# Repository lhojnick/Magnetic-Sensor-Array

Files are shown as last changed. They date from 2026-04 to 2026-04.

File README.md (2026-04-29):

# MAG PCB FINAL — Multi-Sensor Magnetometer Board

**Lab:** Coherent and Quantum Optics Lab, Purdue University  
**PI:** Dr. Elliott  
**Designer:** Luke Hojnicki  
**Primary User:** Chunya Wang  
**KiCad Version:** 10.0.1  
**Status:** Hardware validated, two-board system operational

---

## Overview

This repository contains everything needed to reproduce, operate, and extend the
multi-sensor magnetometer PCB developed for Dr. Elliott's quantum optics lab.

The system measures the 3-axis magnetic field vector (Bx, By, Bz) at **8 spatial
locations simultaneously** using two identical PCBs connected in series via FFC cable.
Each board carries four MMC5983MA AMR magnetometers arranged around a 30 mm radius
circular cutout, allowing the boards to be mounted concentrically around a cylindrical
experimental object (optical tube, glass cell, etc.).

```
Arduino Nano Every
       │
       ├── SDA / SCL / RST / 5V / 3.3V
       │
       ├── Board 0 ─ TCA9546A (0x70) ─┬── MMC5983MA #0  (channel 0)
       │              LM3940 LDO       ├── MMC5983MA #1  (channel 1)
       │                               ├── MMC5983MA #2  (channel 2)
       │                               └── MMC5983MA #3  (channel 3)
       │
       └── Board 1 ─ TCA9546A (0x71) ─┬── MMC5983MA #4  (channel 0)
                      LM3940 LDO       ├── MMC5983MA #5  (channel 1)
                                       ├── MMC5983MA #6  (channel 2)
                                       └── MMC5983MA #7  (channel 3)
```

---

## Repository Structure

```
MAG-PCB/
├── README.md                          ← this file
├── .gitignore
│
├── docs/
│   ├── magnetometer_report.tex        ← full lab report (LaTeX source)
│   ├── magnetometer_report.pdf        ← compiled report
│   └── design_notes.md               ← original circuit design document
│
├── firmware/
│   └── magnetometer/
│       ├── magnetometer.ino           ← main Arduino sketch
│       ├── mmc5983ma.h                ← MMC5983MA driver header
│       └── mmc5983ma.cpp              ← MMC5983MA driver implementation
│
├── python/
│   ├── logger.py                      ← USB-serial data logger (saves CSV)
│   └── requirements.txt
│
└── gerbers/
    ├── MAG PCB FINAL-F_Cu.gbr
    ├── MAG PCB FINAL-B_Cu.gbr
    ├── MAG PCB FINAL-F_Mask.gbr
    ├── MAG PCB FINAL-B_Mask.gbr
    ├── MAG PCB FINAL-F_Paste.gbr
    ├── MAG PCB FINAL-B_Paste.gbr
    ├── MAG PCB FINAL-F_Silkscreen.gbr
    ├── MAG PCB FINAL-B_Silkscreen.gbr
    ├── MAG PCB FINAL-Edge_Cuts.gbr
    └── MAG PCB FINAL-job.gbrjob       ← submit this to fab with all .gbr files
```

---

## Quick Start

### Hardware Setup

1. **Single board:** Connect the Arduino Nano Every to Board 0 via FFC cable.
   Confirm mux address `0x70` with the I2C scanner sketch.

2. **Two boards:** Connect Board 0 PIN_OUT → Board 1 PIN_IN with a
   **Type-B FFC cable** (Top-on-One-Side, Bottom-on-the-Other).
   Board 1 requires the A0 pin on its TCA9546A moved from GND → VCC
   to assign it address `0x71`. See the report (Section 6) for the
   rework procedure.

3. Power-on checklist:
   - Verify 3.3V at LDO output before connecting Arduino
   - Run I2C scanner — expect `0x70` (Board 0) and `0x71` (Board 1)
   - Scan each mux channel — expect `0x30` on all 8 channels

### Firmware

Open `firmware/magnetometer/magnetometer.ino` in Arduino IDE 2.x.

- Board: **Arduino Nano Every** (megaAVR Boards package)
- Registers Emulation: **None (ATMEGA4809)**
- Baud: **115200**

Upload and open Serial Monitor. You should see CSV output:
```
sensorID,Bx_G,By_G,Bz_G
0,0.2341,0.0123,-0.4412
...
7,0.2344,0.0125,-0.4415
```

### Data Logging (Python)

```bash
pip install -r python/requirements.txt
python python/logger.py --port COM3 --output data.csv
# Linux/Mac: --port /dev/ttyACM0
```

---

## Board Specifications

| Parameter | Value |
|---|---|
| Dimensions | 50 mm × 120 mm |
| Layer count | 2 (F_Cu / B_Cu) |
| Board thickness | 1.6 mm |
| Min trace width | 0.3 mm |
| Pad-to-pad clearance | 0.2 mm |
| KiCad version | 10.0.1 |

## I2C Address Map

| Device | Address | Notes |
|---|---|---|
| TCA9546A — Board 0 | `0x70` | A0 = GND (default) |
| TCA9546A — Board 1 | `0x71` | A0 = VCC (requires rework) |
| MMC5983MA (all) | `0x30` | Fixed; isolated per mux channel |

---

## Key Components

| Part | Function | Qty/board |
|---|---|---|
| MMC5983MA | 3-axis AMR magnetometer | 4 |
| TCA9546AD | 4-channel I2C mux | 1 |
| LM3940IMPX | 5V → 3.3V LDO | 1 |
| 2.7 kΩ resistors | I2C pull-ups | 11 |
| 1 µF ceramic caps | Sensor VDD bypass | 4 |
| 10 µF ceramic caps | Sensor CAP pin / mux VCC | 5 |
| 33 µF cap | LDO output | 1 |

---

## Known Issues / Future Work

- INT pin unused — firmware polls Meas_M_Done bit (adequate for ≤10 Hz)
- No on-chip temperature compensation — repeat SET/RESET for long runs
- FFC cable length sensitivity — reduce I2C to 100 kHz for cables > 30 cm
- Max 8 boards (32 sensors) before TCA9546A address space exhausted

---

## References

- MEMSIC MMC5983MA Datasheet, Rev. A
- Texas Instruments TCA9546A Datasheet, SCPS204
- Texas Instruments LM3940 Datasheet, SNOS386
- Arduino Nano Every: https://docs.arduino.cc/hardware/nano-every

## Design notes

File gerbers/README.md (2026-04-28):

# Gerbers

Generated from KiCad 10.0.1 on 2026-04-27.

## Files

| File | Layer | Function |
|---|---|---|
| `MAG PCB FINAL-F_Cu.gbr` | F_Cu (L1) | Top copper — all signal routing |
| `MAG PCB FINAL-B_Cu.gbr` | B_Cu (L2) | Bottom copper — ground/return paths |
| `MAG PCB FINAL-F_Paste.gbr` | F_Paste | Top solder paste (SMT stencil) |
| `MAG PCB FINAL-B_Paste.gbr` | B_Paste | Bottom solder paste |
| `MAG PCB FINAL-F_Silkscreen.gbr` | F_Silkscreen | Top component labels |
| `MAG PCB FINAL-B_Silkscreen.gbr` | B_Silkscreen | Bottom labels |
| `MAG PCB FINAL-F_Mask.gbr` | F_Mask | Top solder mask openings |
| `MAG PCB FINAL-B_Mask.gbr` | B_Mask | Bottom solder mask openings |
| `MAG PCB FINAL-Edge_Cuts.gbr` | Edge_Cuts | Board outline / routed profile |
| `MAG PCB FINAL-job.gbrjob` | — | Gerber job file (submit to fab) |

## Fab Specs (from job file)

- Board size: **50.05 mm × 120.05 mm**
- Layers: **2**
- Thickness: **1.6 mm**
- Min trace: **0.3 mm**
- Pad-to-pad: **0.2 mm**

## Ordering

Submit all `.gbr` files plus the `.gbrjob` to your PCB fabricator
(JLCPCB, PCBWay, OSH Park, etc.). The job file encodes all specifications
automatically.

For two-board assembly: order **2× quantity minimum**. Both boards use
identical Gerbers; the only hardware difference is the A0 address strap
on the TCA9546A (see `docs/magnetometer_report.pdf` Section 6).

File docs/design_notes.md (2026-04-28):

# Magnetometer Array PCB — Circuit Design Notes

**Project:** 4-Channel MMC5983MA Magnetometer Array with I²C Multiplexer  
**Controller:** Arduino Nano Every (ATmega4809)  
**CAD Tool:** KiCad  
**Date:** March 2026  

---

## 1. System Overview

This PCB measures the magnetic field surrounding a laser beam axis using
four MMC5983MA 3-axis magnetometers arranged symmetrically. The sensors are
positioned so that their individual magnetic field contributions cancel
spatially (gradiometric / differential arrangement). The system rapidly
cycles through each sensor using a TCA9546A I²C multiplexer, then computes
an aggregated magnetic field measurement.

---

## 2. Voltage Domain — Critical Design Constraint

**The MMC5983MA has an absolute maximum VDD of 3.6V.**

The Arduino Nano Every USB rail is 5V. The board therefore runs entirely on
the Arduino's 3.3V output pin. All pull-up resistors go to 3.3V, not 5V.

The TCA9546A I/O is 5.5V tolerant so the upstream side can safely interface
with the 5V Arduino, but the I²C pull-ups and all sensor power must be 3.3V.

The ATmega4809 VIH at 5V supply is nominally 3.5V — slightly above 3.3V.
In practice this works reliably due to Schmitt trigger hysteresis on the I²C
pins. If I²C failures occur, add a BSS138 N-channel FET level shifter pair.

**Never connect sensor VDD to the Arduino 5V pin.**

---

## 3. I²C Address Map

| Device | 7-bit Address | Bus Segment |
|---|---|---|
| TCA9546A (Board 0) | 0x70 | Upstream (Arduino bus) |
| TCA9546A (Board 1) | 0x71 | Upstream (Arduino bus) |
| MMC5983MA (all) | 0x30 (fixed) | Downstream, one channel at a time |

No address conflicts exist because each MMC5983MA is isolated on its own
downstream channel. The mux ensures only one sensor is on the upstream bus
at any time.

---

## 4. Pull-Up Resistor Strategy

**Value: 2.7 kΩ** (appropriate for bus lengths < 10 cm at 400 kHz)
**All pull-ups to 3.3V.**

| Bus Segment | SDA pull-up | SCL pull-up |
|---|---|---|
| Upstream (Arduino → mux) | R1 2.7kΩ | R2 2.7kΩ |
| Downstream Ch0 | R3 2.7kΩ | R4 2.7kΩ |
| Downstream Ch1 | R5 2.7kΩ | R6 2.7kΩ |
| Downstream Ch2 | R7 2.7kΩ | R8 2.7kΩ |
| Downstream Ch3 | R9 2.7kΩ | R10 2.7kΩ |

**Total: 10 pull-up resistors per board** (11 on the final design — R3 added
to the upstream SDA net as well).

Each downstream channel needs its own pull-ups because the TCA9546A is a
switch, not a buffer. When a channel is disconnected (switch open), that
downstream segment has no pull-ups unless they are present locally.

---

## 5. TCA9546A Channel Select Sequence

To read sensor N (0–3):

1. Write to TCA9546A (0x70): control byte = `(1 << N)` — enable channel N only
2. Communicate with MMC5983MA (0x30) — reaches only sensor N
3. Read measurement data
4. Write `0x00` to TCA9546A to deselect all channels
5. Repeat for next sensor

```
Write 0x70: 0x01  →  Read sensor 0 at 0x30
Write 0x70: 0x02  →  Read sensor 1 at 0x30
Write 0x70: 0x04  →  Read sensor 2 at 0x30
Write 0x70: 0x08  →  Read sensor 3 at 0x30
```

**Important:** A STOP condition must follow the control register write
before communicating with the downstream device (TCA9546A datasheet p14).

---

## 6. MMC5983MA Decoupling

Per datasheet application circuit:

| Pin | Cap | Value | Placement |
|-----|-----|---|---|
| VDD (pin 2) | Bypass | 1 µF | As close as possible to sensor |
| CAP (pin 10) | Required | 10 µF | Low-ESR ceramic; internal charge pump ref |

Do not omit the CAP pin capacitor — it is required for the internal charge
pump that drives the SET/RESET coil. The sensor will not function correctly
without it.

---

## 7. SET/RESET Coil Operation

The MMC5983MA contains an on-chip coil for re-magnetizing the Permalloy
sensing element. This is required to:

- Restore the sensor after exposure to strong external fields (SET)
- Enable offset cancellation via bridge output subtraction (SET + RESET)

**SET** (CONTROL0 bit 3 = 1):
- Magnetizes Permalloy in positive direction
- Issue at startup and periodically during long runs

**RESET** (CONTROL0 bit 4 = 1):
- Magnetizes Permalloy in negative direction
- Combined with SET measurement: B = (B_SET - B_RESET) / 2
- Cancels temperature-dependent bridge offset

Wait ≥ 1 µs after each pulse before triggering a measurement.

---

## 8. Fast I²C Polling Strategy

Target: ~1 kHz aggregate sample rate across all 4 sensors (250 Hz per sensor).

At 400 kHz I²C (Fast Mode):
- Channel select write: ~25 µs
- Measurement trigger + 2 ms conversion time (dominant)
- 7-byte burst read (18-bit output): ~20 µs
- Channel deselect: ~25 µs

Per-sensor total: ~2.1 ms → **~470 Hz per sensor / ~120 Hz aggregate**

To achieve higher rates: use CONTROL1 BW[1:0] = 0b11 (highest bandwidth,
lowest conversion time ~0.5 ms), or enable Continuous Measurement Mode
(CMM_EN) and poll status bit rather than triggering each time.

---

## 9. Layout Rules for Magnetic Quiet Zone

1. **No current loops near sensors.** All routing that carries meaningful
   current (power, USB, regulator) must be in the control section,
   physically separated from the sensor array.

2. **Tight bypass caps.** Place VDD and CAP bypass caps within 1 mm of
   sensor pads to minimize high-frequency current loop area.

3. **No ferromagnetic components** in the sensor section. Ceramic caps only.

4. **Bundle I²C channel traces** through any routing neck. Keep SDA/SCL
   pairs adjacent to minimize differential loop area.

5. **Mounting holes:** Use non-magnetic hardware (brass or nylon).
   Stainless steel screws near sensors will perturb readings.

---

## 10. Design Assumptions

- Arduino Nano Every operates at 5V USB; 3.3V rail supplies sensor circuit.
- Only one TCA9546A channel enabled at a time (no simultaneous operation).
- Laser environment does not produce fields exceeding ±8 G (sensor FSR).
- Room temperature operation (20–25°C); all parts rated to −40/+85°C.
- MMC5983MA SPI_SDO pin left floating in I²C mode (consistent with
  MEMSIC application circuit, p10–11 of datasheet).
- INT pins unused; firmware polls Meas_M_Done status bit.

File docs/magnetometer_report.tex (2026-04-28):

\documentclass[12pt]{article}

% ── Packages ──────────────────────────────────────────────────────────────────
\usepackage[margin=1in]{geometry}
\usepackage{graphicx}
\usepackage{float}
\usepackage{amsmath}
\usepackage{hyperref}
\usepackage{listings}
\usepackage{xcolor}
\usepackage{booktabs}
\usepackage{caption}
\usepackage{subcaption}
\usepackage{fancyhdr}
\usepackage{titlesec}
\usepackage{parskip}
\usepackage{enumitem}
\usepackage{siunitx}
\usepackage{array}
\usepackage{multirow}

% ── Code listing style ────────────────────────────────────────────────────────
\lstset{
  basicstyle=\ttfamily\small,
  keywordstyle=\color{blue!70!black},
  commentstyle=\color{gray},
  stringstyle=\color{red!70!black},
  numbers=left,
  numberstyle=\tiny\color{gray},
  frame=single,
  breaklines=true,
  captionpos=b,
  tabsize=2
}

% ── Header / Footer ───────────────────────────────────────────────────────────
\setlength{\headheight}{15pt}
\pagestyle{fancy}
\fancyhf{}
\rhead{Coherent \& Quantum Optics Lab --- Purdue ECE}
\lhead{Multi-Sensor Magnetometer PCB}
\rfoot{Page \thepage}

% ── Hyperlink colors ──────────────────────────────────────────────────────────
\hypersetup{
  colorlinks=true,
  linkcolor=blue!60!black,
  urlcolor=blue!60!black,
  citecolor=green!50!black
}

\graphicspath{{figures/}}

% ══════════════════════════════════════════════════════════════════════════════
\begin{document}

% ── Title Page ────────────────────────────────────────────────────────────────
\begin{titlepage}
  \centering
  \vspace*{2cm}
  {\LARGE\bfseries Multi-Sensor Magnetometer PCB\\[0.4em]
  \large Design, Operation, and Programming Reference\par}
  \vspace{1.5cm}
  {\large Luke Hojnicki\\
  Coherent and Quantum Optics Lab\\
  Dr.\ Elliott, Purdue University\\[0.5em]
  \today}
  \vfill
  \textit{Prepared for internal lab use. Intended audience: future lab members
  and primary user Chunya Wang.}
\end{titlepage}

% ── Table of Contents ─────────────────────────────────────────────────────────
\tableofcontents
\listoffigures
\listoftables
\newpage

% ══════════════════════════════════════════════════════════════════════════════
\section{Introduction and Purpose}

\subsection{Background}

This document describes the design, assembly, and operation of the
Magnetometer PCB developed for Dr.\ Elliott's Coherent and Quantum Optics Lab
at Purdue University. The board enables simultaneous, high-resolution
measurement of magnetic field vectors at multiple spatial positions, which is
required for Chunya Wang's experimental work characterizing magnetic field
distributions in the lab environment.

The system measures the three-dimensional magnetic field ($B_x$, $B_y$,
$B_z$) at up to eight locations using MEMSIC MMC5983MA AMR sensors arranged
across two identical PCBs connected in series via a flat flexible cable (FFC).
Each board hosts four sensors multiplexed over a single I$^2$C bus and is
controlled by a shared Arduino Nano Every microcontroller.

\subsection{Design Goals}

\begin{itemize}
  \item Simultaneous readout of 8 MMC5983MA sensors (4 per board, 2 boards)
  \item Single Arduino Nano Every host controller over a shared I$^2$C bus
  \item On-board 5\,V to 3.3\,V regulation; boards powered from the Arduino's
        USB supply
  \item Daisy-chain expansion via FFC connector (Top-on-One-Side /
        Bottom-on-the-Other cable type)
  \item Address conflict resolution between boards via hardware address
        strapping on the TCA9546A multiplexer
  \item Minimal magnetic interference from PCB-generated fields
        (see Section~\ref{sec:layout})
\end{itemize}

\subsection{Scope of This Document}

This document covers: (1) hardware overview and component descriptions,
(2) full circuit schematics, (3) PCB layout notes, (4) assembly and setup,
(5) programming the board, (6) reading and interpreting sensor data, and
(7) troubleshooting. A future student or Chunya should be able to bring the
system from unpowered to collecting data using only this document.

\newpage
% ══════════════════════════════════════════════════════════════════════════════
\section{System Architecture}

\subsection{Block Diagram}

Figure~\ref{fig:block} shows the full two-board system. The Arduino Nano Every
acts as the I$^2$C master. Both boards share the same SDA, SCL, RST, +5\,V,
and +3.3\,V lines routed through the FFC connector. Each board contains an
LM3940 voltage regulator, one TCA9546A I$^2$C multiplexer, and four
MMC5983MA sensors.

\begin{figure}[H]
  \centering
  
  \caption{Full system block diagram. The Arduino Nano Every drives two
  identical sensor boards (Board~0 and Board~1) via a shared FFC bus.}
  \label{fig:block}
\end{figure}

\subsection{Top-Level Schematic}

Figure~\ref{fig:sch_top} shows the top-level KiCad schematic for one board.
The FFC connector routes RST, SCL, SDA, and the four mux channel pairs
(SC0/SD0 through SC3/SD3) to the TCA9546A sub-sheet and the four MMC
sub-sheets. Two mounting holes (H1, H2) are also indicated.

\begin{figure}[H]
  \centering
  
  \caption{Top-level schematic showing FFC connector, TCA9546A, and four
  MMC5983MA instances (one board).}
  \label{fig:sch_top}
\end{figure}

\newpage
% ══════════════════════════════════════════════════════════════════════════════
\section{Component Descriptions}

\subsection{Component Summary}

\begin{table}[H]
  \centering
  \caption{Key Components (per board)}
  \begin{tabular}{llll}
    \toprule
    \textbf{Component} & \textbf{Part Number} & \textbf{Qty} &
    \textbf{Function} \\
    \midrule
    Magnetic field sensor   & MMC5983MA    & 4 & 3-axis AMR magnetometer \\
    I$^2$C multiplexer      & TCA9546AD    & 1 & 4-channel bus switch \\
    Voltage regulator       & LM3940IMPX   & 1 & 5\,V $\to$ 3.3\,V LDO \\
    FFC connector (in/out)  & \textit{[PN]} & 2 & Board-to-board bus \\
    Bulk output cap         & 33\,\textmu F & 1 & LDO output decoupling \\
    Mux bypass cap          & 10\,\textmu F & 1 & TCA9546A VCC \\
    Sensor VDD bypass cap   & 1\,\textmu F & 4 & MMC5983MA VDD \\
    Sensor CAP bypass cap   & 10\,\textmu F & 4 & MMC5983MA CAP pin \\
    I$^2$C pull-up resistors & 2.7\,k$\Omega$ & 11 & All SDA/SCL lines \\
    \bottomrule
  \end{tabular}
  \label{tab:components}
\end{table}

\subsection{MMC5983MA Magnetic Field Sensor}

The MMC5983MA (MEMSIC) is a 3-axis anisotropic magnetoresistance (AMR)
magnetic field sensor housed in a $2.0 \times 2.0 \times 1.0$\,mm LGA-16
package. It measures $B_x$, $B_y$, and $B_z$ simultaneously and communicates
over I$^2$C at a single fixed address of \texttt{0x30}. Key specifications
are listed in Table~\ref{tab:mmc_specs}.

\begin{table}[H]
  \centering
  \caption{MMC5983MA Key Specifications \cite{mmc5983ma}}
  \begin{tabular}{lll}
    \toprule
    \textbf{Parameter} & \textbf{Value} & \textbf{Notes} \\
    \midrule
    Supply voltage (VDD)       & 1.71--3.6\,V               & \\
    Full-scale range           & $\pm$8\,G                  & \\
    Resolution (18-bit mode)   & 0.0625\,mG/LSB             & 18-bit output \\
    RMS noise                  & 0.4\,mG (typ.)             & Continuous mode \\
    Output data rate           & up to \SI{1000}{\hertz}    & \\
    I$^2$C address             & \texttt{0x30} (fixed)      & \\
    Operating temperature      & $-40$ to $+85$\,\textdegree C & \\
    Package                    & LGA-16, $2.0 \times 2.0$\,mm & \\
    \bottomrule
  \end{tabular}
  \label{tab:mmc_specs}
\end{table}

\subsubsection{Pin Configuration and Connections}

In this design the MMC5983MA is used exclusively in I$^2$C mode.
Table~\ref{tab:mmc_pins} lists the relevant pin assignments; SPI-only pins
(SPL\_CS, SPL\_SDO) are left unconnected (NC).

\begin{table}[H]
  \centering
  \caption{MMC5983MA Pin Assignment (this design)}
  \begin{tabular}{lllp{6cm}}
    \toprule
    \textbf{Pin} & \textbf{Name} & \textbf{Connected to} &
    \textbf{Notes} \\
    \midrule
    1  & SCL/SPL\_SCK & SCx (from mux channel) & I$^2$C clock \\
    2  & VDD          & +3.3\,V via 1\,\textmu F cap & Supply \\
    3  & NC           & ---                    & \\
    4  & NC           & ---                    & \\
    5  & SPL\_CS      & NC                     & SPI not used \\
    6  & SPL\_SDO     & NC                     & SPI not used \\
    7--8 & NC         & ---                    & \\
    9  & GND          & GND                    & \\
    10 & CAP          & GND via 10\,\textmu F  & Internal charge pump ref \\
    11 & GND          & GND                    & \\
    12 & NC           & ---                    & \\
    13 & VDDIO        & +3.3\,V                & I/O voltage \\
    14 & NC           & ---                    & \\
    15 & INT          & NC                     & Interrupt not used \\
    16 & SDA/SPL\_SDI & SDx (from mux channel) & I$^2$C data \\
    \bottomrule
  \end{tabular}
  \label{tab:mmc_pins}
\end{table}

\subsubsection{SET/RESET Coil}

The MMC5983MA contains an on-chip SET/RESET coil that drives a large current
pulse through the sensing element to re-magnetize the Permalloy film in a
known direction. This is necessary because:

\begin{itemize}
  \item \textbf{SET} magnetizes the film in the ``positive'' direction,
        establishing a known reference state and removing any negative offset
        from strong external field exposure.
  \item \textbf{RESET} magnetizes the film in the opposite direction.
        Taking the difference of a SET and RESET measurement,
        $B = (B_\text{SET} - B_\text{RESET})/2$, cancels the
        temperature-dependent bridge offset, substantially improving accuracy.
\end{itemize}

A SET or RESET pulse is issued by writing the corresponding bit in the
\texttt{CONTROL\_0} register (\texttt{0x09}). The firmware must wait at
least \SI{1}{\micro\second} after the pulse before issuing a measurement
command. See Section~\ref{sec:setresetproc} for the recommended procedure.

\subsubsection{Fixed I\textsuperscript{2}C Address and the Multiplexer Requirement}

Because all MMC5983MA devices share the fixed I$^2$C address \texttt{0x30},
placing more than one sensor on a single bus causes address collisions.
The TCA9546A multiplexer resolves this by isolating each sensor on its own
switched bus segment, presenting only one sensor to the master at a time.

\subsection{TCA9546A I\textsuperscript{2}C Multiplexer}
\label{subsec:tca}

The TCA9546AD (Texas Instruments) is a low-voltage 4-channel I$^2$C bus
switch in a VSSOP-10 package. It sits between the Arduino Nano Every (I$^2$C
master) and the four MMC5983MA sensors, enabling the master to address each
sensor individually by enabling only one downstream channel at a time.

\subsubsection{I\textsuperscript{2}C Address Strapping}

The TCA9546A I$^2$C address is determined by the logic levels on address
pins A0--A2 (pins 1, 2, 13 in the schematic). The base address is
\texttt{0b1110\_xxx} where \texttt{xxx = A2A1A0}, giving the range
\texttt{0x70}--\texttt{0x77}.

On this board, A2 and A1 are tied to GND. A0 is the address differentiation
pin used to distinguish Board~0 from Board~1:

\begin{table}[H]
  \centering
  \caption{TCA9546A Address Strapping per Board}
  \begin{tabular}{lllll}
    \toprule
    \textbf{Board} & \textbf{A2} & \textbf{A1} & \textbf{A0} &
    \textbf{I$^2$C Address} \\
    \midrule
    Board 0 & GND & GND & GND & \texttt{0x70} \\
    Board 1 & GND & GND & VCC & \texttt{0x71} \\
    \bottomrule
  \end{tabular}
  \label{tab:tca_addr}
\end{table}

\textbf{Important:} Both boards ship with A0 tied to GND (\texttt{0x70}).
When connecting two boards in series, the A0 pin on Board~1's TCA9546A
must be moved from GND to VCC to assign it address \texttt{0x71}. This
is a solder bridge or jumper change on the board. See
Section~\ref{sec:twoboard} for the two-board setup procedure.

\subsubsection{Channel Select Register}

The TCA9546A is controlled by writing a single byte to its I$^2$C address.
Bits [3:0] enable channels 0--3 respectively; only one bit should be set
at a time. Writing \texttt{0x00} disconnects all channels (recommended
after each read to prevent bus contention).

\begin{table}[H]
  \centering
  \caption{TCA9546A Channel Select Byte}
  \begin{tabular}{lll}
    \toprule
    \textbf{Channel} & \textbf{Byte (hex)} & \textbf{Sensor} \\
    \midrule
    0 & \texttt{0x01} & U4 / MMC\_0 \\
    1 & \texttt{0x02} & U3 / MMC\_1 \\
    2 & \texttt{0x04} & U5 / MMC\_2 \\
    3 & \texttt{0x08} & U6 / MMC\_3 \\
    None & \texttt{0x00} & All disconnected \\
    \bottomrule
  \end{tabular}
  \label{tab:tca_select}
\end{table}

\subsubsection{Pull-up Resistors}

Each I$^2$C segment has dedicated pull-up resistors to +3.3\,V. The values
used are $2.7\,\text{k}\Omega$ throughout (R1--R11), consistent with
\SI{400}{\kilo\hertz} Fast-Mode operation at the expected bus capacitances.
Specifically:

\begin{itemize}
  \item R1, R2, R3: upstream SDA, SCL, and one additional line
  \item R4/R5, R6/R7, R8/R9, R10/R11: downstream SDA/SCL pairs for
        channels 0--3 (SD0/SC0 through SD3/SC3)
\end{itemize}

\subsubsection{Bypass Capacitor}

A 10\,\textmu F capacitor (C1) is placed on the TCA9546A VCC pin for
bulk decoupling.

\subsubsection{RESET Pin}

The TCA9546A \texttt{/RESET} pin is connected to the RST net from the FFC
connector, which is driven by the Arduino Nano Every. Asserting this pin
low disconnects all channels and resets the channel select register to
\texttt{0x00}. This allows the firmware to perform a hardware bus reset
without power-cycling the entire board.

\subsection{LM3940IMPX Voltage Regulator}

The LM3940IMPX (U2) is a low-dropout (LDO) linear regulator that converts
the 5\,V supply from the Arduino Nano Every USB rail to the 3.3\,V required
by the TCA9546A and MMC5983MA sensors. A 33\,\textmu F output capacitor
(C2) provides output stabilization and transient suppression as specified
in the LM3940 datasheet. Both GND pins of the regulator are connected to
the board ground plane. \textbf{Do not power the sensor VDD from the
Arduino's 5\,V pin directly.}

\subsection{FFC Connector and Daisy-Chain Bus}

Each board has two FFC connectors (J4 PIN\_IN, J1 PIN\_OUT) for daisy-chain
expansion. The 16-pin connector carries the following signals:

\begin{table}[H]
  \centering
  \caption{FFC Connector Pinout}
  \begin{tabular}{lll}
    \toprule
    \textbf{Pin(s)} & \textbf{Signal} & \textbf{Notes} \\
    \midrule
    1, 2, 15, 16 & GND       & Ground \\
    3            & +5V       & Arduino USB rail \\
    7            & SCL       & I$^2$C clock (shared bus) \\
    10           & SDA       & I$^2$C data (shared bus) \\
    12           & RST       & Active-low mux reset \\
    14           & +3.3V     & Regulated output from LM3940 \\
    4--6, 8--9, 11, 13 & NC  & Not connected \\
    \bottomrule
  \end{tabular}
  \label{tab:ffc_pins}
\end{table}

\textbf{Cable orientation note:} The FFC cable used in this system is of the
``Top-on-One-Side, Bottom-on-the-Other'' (Type B) variety. This means the
contacts on one end face up and the contacts on the other end face down.
Ensure the cable is inserted into each connector in the correct orientation
to avoid a pin-reversal short. When connecting Board~0 PIN\_OUT to
Board~1 PIN\_IN, verify that power and signal nets align before applying
power.

\subsection{Arduino Nano Every}

The Arduino Nano Every serves as the I$^2$C master and USB-serial interface.
It is based on the ATmega4809 microcontroller, operates at \SI{20}{\mega\hertz},
and provides 3.3\,V-compatible I/O.

\begin{table}[H]
  \centering
  \caption{Arduino Nano Every Key Specifications}
  \begin{tabular}{ll}
    \toprule
    \textbf{Parameter} & \textbf{Value} \\
    \midrule
    Microcontroller    & ATmega4809 \\
    CPU speed          & \SI{20}{\mega\hertz} \\
    Flash / SRAM       & 48\,kB / 6\,kB \\
    I$^2$C pins        & A4 (SDA), A5 (SCL) \\
    I$^2$C speed       & Standard (100\,kHz) / Fast (400\,kHz) \\
    USB interface      & USB CDC via SAMD11 co-processor \\
    \bottomrule
  \end{tabular}
  \label{tab:nano_specs}
\end{table}

The Nano Every's A4/A5 pins connect to the shared SDA/SCL bus. A digital
output pin connects to the RST net for hardware mux resets. The board is
powered from USB; the on-board 3.3\,V regulator output is also forwarded to
the sensor boards via the FFC connector.

Upload instructions: select \textbf{Arduino Nano Every} under
\textit{Tools $\rightarrow$ Board $\rightarrow$ Arduino megaAVR Boards},
set \textit{Registers Emulation} to \textbf{None (ATMEGA4809)}, select
the correct COM port, and click Upload.

\newpage
% ══════════════════════════════════════════════════════════════════════════════
\section{Circuit Schematics}

\subsection{Power Distribution}
\label{sec:power_sch}

Figure~\ref{fig:sch_power} shows the power and connector schematic. The
LM3940IMPX (U2) receives +5\,V from the FFC connector (J4 PIN\_IN, pin 3)
and outputs +3.3\,V (VCC net) stabilized by a 33\,\textmu F capacitor (C2).
The regulated +3.3\,V is also forwarded to the PIN\_OUT connector (J1) so
that it is available to downstream boards in the daisy chain. SCL, SDA,
RST, and GND are passed through both connectors unchanged.

\begin{figure}[H]
  \centering
  
  \caption{Power distribution and FFC connector schematic. U2 (LM3940IMPX)
  converts +5\,V to +3.3\,V (VCC). J4 is the input FFC connector;
  J1 passes signals to the next board in the chain.}
  \label{fig:sch_power}
\end{figure}

\subsection{I\textsuperscript{2}C Multiplexer (TCA9546A)}

Figure~\ref{fig:sch_mux} shows the TCA9546A multiplexer schematic. The
upstream SDA and SCL lines from the FFC connector enter pins 15 and 14
of U1 respectively, with $2.7\,\text{k}\Omega$ pull-ups (R1--R3) to VCC.
Each of the four downstream channel pairs (SD0/SC0 through SD3/SC3) has
its own $2.7\,\text{k}\Omega$ pull-up pair to +3.3\,V (R4--R11). Address
pins A2 and A1 (pins 13 and 2) are tied to GND; A0 (pin 1) determines
the board address (GND = \texttt{0x70}, VCC = \texttt{0x71}). The RESET
pin (pin 3) is driven by the RST net from the FFC connector.

\begin{figure}[H]
  \centering
  
  \caption{TCA9546AD I$^2$C multiplexer schematic. All pull-ups are
  $2.7\,\text{k}\Omega$ to +3.3\,V. A0 straps select the board I$^2$C
  address (see Table~\ref{tab:tca_addr}).}
  \label{fig:sch_mux}
\end{figure}

\subsection{MMC5983MA Sensor Instances}

All four sensors per board are identical circuits; they differ only in which
mux channel they connect to (SC0/SD0 through SC3/SD3). Each sensor has:
a 1\,\textmu F bypass capacitor on VDD (pins C5, C3, C7, C9 for sensors
0--3) and a 10\,\textmu F capacitor on the CAP pin (C6, C4, C8, C10) to
GND, as required by the MMC5983MA datasheet. SPL\_CS and SPL\_SDO are left
unconnected to select I$^2$C mode. The INT pin is not connected as interrupt-
driven acquisition is not used in this implementation.

\begin{figure}[H]
  \centering
  \begin{subfigure}[b]{0.48\textwidth}
    
    \caption{U4 / MMC\_0 (channel 0, SC0/SD0)}
  \end{subfigure}
  \hfill
  \begin{subfigure}[b]{0.48\textwidth}
    
    \caption{U3 / MMC\_1 (channel 1, SC1/SD1)}
  \end{subfigure}
  \\[1em]
  \begin{subfigure}[b]{0.48\textwidth}
    
    \caption{U5 / MMC\_2 (channel 2, SC2/SD2)}
  \end{subfigure}
  \hfill
  \begin{subfigure}[b]{0.48\textwidth}
    
    \caption{U6 / MMC\_3 (channel 3, SC3/SD3)}
  \end{subfigure}
  \caption{MMC5983MA sensor schematics. All four instances are identical;
  each is isolated on its own TCA9546A downstream channel.}
  \label{fig:sch_sensors}
\end{figure}

\newpage
% ══════════════════════════════════════════════════════════════════════════════
\section{PCB Layout}
\label{sec:layout}

\subsection{Board Overview}

The PCB measures \textbf{50.05\,mm $\times$ 120.05\,mm} and uses a
\textbf{2-layer stackup} (F\_Cu / B\_Cu) on a standard 1.6\,mm FR4 substrate.
It was designed in KiCad~10.0.1. The board outline has a distinctive
hourglass profile: a wider octagonal control section at the top, a narrow
routing neck in the middle, and a wider octagonal sensor section at the
bottom with a large circular cutout at its center.

\begin{table}[H]
  \centering
  \caption{PCB Fabrication Specifications}
  \begin{tabular}{ll}
    \toprule
    \textbf{Parameter} & \textbf{Value} \\
    \midrule
    Board dimensions    & 50.05\,mm $\times$ 120.05\,mm \\
    Layer count         & 2 (F\_Cu top, B\_Cu bottom) \\
    Board thickness     & 1.6\,mm \\
    Min trace width     & 0.3\,mm \\
    Pad-to-pad clearance & 0.2\,mm \\
    Pad-to-track clearance & 0.2\,mm \\
    Surface finish      & \textit{[HASL / ENIG / specify]} \\
    \bottomrule
  \end{tabular}
  \label{tab:fab_specs}
\end{table}

\subsection{Top and Bottom Copper Layers}

\begin{figure}[H]
  \centering
  \begin{subfigure}[b]{0.45\textwidth}
    
    \caption{Top copper (F\_Cu, red) with silkscreen.}
  \end{subfigure}
  \hfill
  \begin{subfigure}[b]{0.45\textwidth}
    
    \caption{Bottom copper (B\_Cu, blue).}
  \end{subfigure}
  \caption{PCB layout rendered from Gerber files. Top layer carries nearly
  all routing; the bottom layer provides a partial ground plane and return
  paths.}
  \label{fig:pcb_layers}
\end{figure}

\subsection{Board Shape and Functional Regions}

The board is divided into three functional regions:

\begin{enumerate}
  \item \textbf{Control section (top octagon):} Houses the two FFC
        connectors, the LM3940IMPX regulator (U2) with its 33\,\textmu F
        output cap (C2), the TCA9546A multiplexer (U1) with its 10\,\textmu F
        bypass cap (C1), and all 11 pull-up resistors (R1--R11). Two
        mounting holes are located at the top corners of this section.

  \item \textbf{Routing neck (center):} A narrow bridge carrying the eight
        I$^2$C channel traces (SD0--SD3, SC0--SC3) from the multiplexer
        to the sensor section. Keeping these traces confined to the neck
        minimizes the copper area in the magnetically sensitive sensor
        region.

  \item \textbf{Sensor section (bottom octagon):} Contains the four
        MMC5983MA sensors (U3--U6) and their associated bypass capacitors
        (C3--C10), arranged around a large circular cutout
        (approximately 30\,mm radius / 60\,mm diameter). The cutout allows
        the board to be mounted concentrically around a cylindrical
        experimental object such as a glass cell or optical tube.
\end{enumerate}

\subsection{Sensor Placement Around the Circular Cutout}

The four sensors are positioned at the cardinal points of the circular
cutout to provide spatially distributed field measurements around the
mounted object:

\begin{table}[H]
  \centering
  \caption{Sensor Positions Around Circular Cutout}
  \begin{tabular}{llll}
    \toprule
    \textbf{Ref.} & \textbf{Channel} & \textbf{Clock position} &
    \textbf{Notes} \\
    \midrule
    U3 & 1 (SC1/SD1) & 12 o'clock (top)    & \\
    U4 & 0 (SC0/SD0) & 9 o'clock (left)    & \\
    U6 & 3 (SC3/SD3) & 3 o'clock (right)   & \\
    U5 & 2 (SC2/SD2) & 6 o'clock (bottom)  & \\
    \bottomrule
  \end{tabular}
  \label{tab:sensor_positions}
\end{table}

Each sensor is oriented with its package aligned to the board axes. If
absolute field direction relative to the mounted object is required,
the orientation of each sensor's $X$, $Y$, $Z$ axes relative to the
board frame should be recorded when installing the board in the
experimental apparatus.

\subsection{Magnetic Noise Minimization}

The following layout decisions were made to minimize PCB-generated magnetic
interference at the sensor locations:

\begin{itemize}
  \item \textbf{Functional isolation:} All active components that carry
        significant current (regulator, mux, connectors) are confined to
        the control section, physically separated from the sensors by the
        narrow neck. This puts the largest current loops as far as possible
        from the sensor LGAs.
  \item \textbf{Bypass cap proximity:} Each sensor's 1\,\textmu F VDD cap
        and 10\,\textmu F CAP pin cap are placed immediately adjacent to the
        sensor pads, minimizing the loop area of high-frequency switching
        currents.
  \item \textbf{No ferromagnetics near sensors:} All passive components in
        the sensor section are ceramic capacitors; no inductors or
        ferrite-core components are placed in the bottom octagon.
  \item \textbf{Trace routing in neck:} The I$^2$C channel traces are
        bundled tightly through the neck and routed as differential-pair-like
        groups (SDA/SCL per channel adjacent) to reduce loop area and
        radiated field.
  \item \textbf{Silkscreen note:} The board carries a ``BOILER UP!!''
        silkscreen label on the control section --- this is cosmetic only
        and has no electrical significance.
\end{itemize}

\newpage
% ══════════════════════════════════════════════════════════════════════════════
\section{Assembly and Setup}

\subsection{Bill of Materials (BOM)}

\begin{table}[H]
  \centering
  \caption{Bill of Materials (one board)}
  \begin{tabular}{lllll}
    \toprule
    \textbf{Ref.} & \textbf{Value / PN} & \textbf{Qty} &
    \textbf{Function} & \textbf{Supplier} \\
    \midrule
    U1          & TCA9546AD      & 1 & I$^2$C mux       & \textit{[TI / Digikey]} \\
    U2          & LM3940IMPX     & 1 & 5V$\to$3.3V LDO  & \textit{[TI / Digikey]} \\
    U3--U6      & MMC5983MA      & 4 & 3-axis sensor    & \textit{[MEMSIC / Digikey]} \\
    J1, J4      & FFC 16-pin     & 2 & Board connector  & \textit{[PN]} \\
    C1          & 10\,\textmu F  & 1 & TCA VCC bypass   & \textit{[PN]} \\
    C2          & 33\,\textmu F  & 1 & LDO output cap   & \textit{[PN]} \\
    C3, C5, C7, C9 & 1\,\textmu F & 4 & Sensor VDD bypass & \textit{[PN]} \\
    C4, C6, C8, C10 & 10\,\textmu F & 4 & Sensor CAP pin & \textit{[PN]} \\
    R1--R11     & 2.7\,k$\Omega$ & 11 & I$^2$C pull-ups & \textit{[PN]} \\
    H1, H2      & Mounting hole  & 2  & Mechanical      & --- \\
    \bottomrule
  \end{tabular}
  \label{tab:bom}
\end{table}

\subsection{Soldering Notes}

\begin{itemize}
  \item The MMC5983MA and TCA9546AD are LGA/VSSOP packages that require
        reflow soldering. Hand-soldering is possible for the VSSOP but
        not recommended for the LGA sensors.
  \item Apply flux generously under LGA pads before placing components.
  \item After reflow, inspect all sensor and mux connections with a
        microscope or loupe. Tombstoned or bridged pads will cause
        I$^2$C failures.
  \item The LM3940IMPX is a through-hole or SMD package (verify footprint);
        solder last to avoid heat damage to nearby sensors.
\end{itemize}

\subsection{Initial Power-On Checklist}

\begin{enumerate}
  \item \textbf{Before connecting the Arduino:} Measure the +3.3\,V output
        of U2 with a DMM. It should read $3.3\,\text{V} \pm 0.1\,\text{V}$.
        If it reads 0\,V or 5\,V, check U2 orientation and C2 polarity.
  \item Verify that SDA and SCL have \SI{3.3}{\volt} pull-ups by measuring
        them at rest (should read $\approx3.3\,\text{V}$ with no activity).
  \item Connect the Arduino and upload the I$^2$C scanner sketch
        (Section~\ref{sec:i2c_scan}).
  \item Confirm that \texttt{0x70} (Board 0 mux) appears in the scan.
        If running two boards, also confirm \texttt{0x71} (Board 1 mux).
  \item Select each mux channel in turn and verify that \texttt{0x30}
        (MMC5983MA) appears on each channel. Eight total hits expected
        for the two-board system.
  \item Run the test firmware and confirm plausible field readings
        ($\pm$ambient Earth field, roughly 0.2--0.6\,G depending on
        orientation).
\end{enumerate}

\newpage
% ══════════════════════════════════════════════════════════════════════════════
\section{Two-Board Setup}
\label{sec:twoboard}

\subsection{Overview}

Two identical boards are connected in series via an FFC cable to provide
eight sensor channels total. The Arduino Nano Every drives both boards over
the same SDA, SCL, RST, and power lines. The two TCA9546A multiplexers are
differentiated by I$^2$C address:

\begin{itemize}
  \item \textbf{Board 0:} Mux address \texttt{0x70} (A0 = GND,
        factory default)
  \item \textbf{Board 1:} Mux address \texttt{0x71} (A0 = VCC,
        requires hardware modification)
\end{itemize}

\subsection{Hardware Modification for Board 1}

On Board 1's TCA9546A (U1), the A0 pin must be changed from GND to VCC:

\begin{enumerate}
  \item Identify the A0 pad on U1 (pin 1 of TCA9546AD; see
        Figure~\ref{fig:sch_mux}).
  \item Remove or cut the GND connection to A0.
  \item Bridge A0 to the VCC net (3.3\,V). A short wire or solder
        bridge to the adjacent VCC pad is sufficient.
  \item After the modification, confirm with an ohmmeter that A0 is
        connected to VCC and isolated from GND.
\end{enumerate}

\subsection{FFC Cable Connection}

\begin{enumerate}
  \item Use a Type-B FFC cable (Top-on-One-Side, Bottom-on-the-Other).
        This type is required because the PIN\_OUT connector on one board
        faces opposite to the PIN\_IN connector on the next.
  \item Insert one end of the cable into Board 0's PIN\_OUT connector (J1).
        The contacts should face the correct direction for the ZIF/LIF latch
        on that connector.
  \item Insert the other end into Board 1's PIN\_IN connector (J4).
  \item \textbf{Before powering on:} double-check that the +5\,V, +3.3\,V,
        GND, SDA, and SCL pins map correctly across the connector. A pin
        reversal will short power to GND.
\end{enumerate}

\subsection{Sensor Numbering Convention}

With both boards connected, the eight sensors are addressed as follows:

\begin{table}[H]
  \centering
  \caption{Full 8-Sensor Addressing Map}
  \begin{tabular}{lllll}
    \toprule
    \textbf{Logical ID} & \textbf{Board} & \textbf{Mux addr} &
    \textbf{Channel} & \textbf{Sensor I$^2$C addr} \\
    \midrule
    Sensor 0 & Board 0 & \texttt{0x70} & 0 (\texttt{0x01}) & \texttt{0x30} \\
    Sensor 1 & Board 0 & \texttt{0x70} & 1 (\texttt{0x02}) & \texttt{0x30} \\
    Sensor 2 & Board 0 & \texttt{0x70} & 2 (\texttt{0x04}) & \texttt{0x30} \\
    Sensor 3 & Board 0 & \texttt{0x70} & 3 (\texttt{0x08}) & \texttt{0x30} \\
    Sensor 4 & Board 1 & \texttt{0x71} & 0 (\texttt{0x01}) & \texttt{0x30} \\
    Sensor 5 & Board 1 & \texttt{0x71} & 1 (\texttt{0x02}) & \texttt{0x30} \\
    Sensor 6 & Board 1 & \texttt{0x71} & 2 (\texttt{0x04}) & \texttt{0x30} \\
    Sensor 7 & Board 1 & \texttt{0x71} & 3 (\texttt{0x08}) & \texttt{0x30} \\
    \bottomrule
  \end{tabular}
  \label{tab:sensor_map}
\end{table}

\newpage
% ══════════════════════════════════════════════════════════════════════════════
\section{Programming the Board}

\subsection{Development Environment}

\begin{itemize}
  \item Arduino IDE 2.x (or 1.8.x)
  \item Board package: \textit{Arduino megaAVR Boards} (install via
        Boards Manager, search ``megaAVR'')
  \item Required libraries: \texttt{Wire} (built-in),
        \textit{[MMC5983MA library --- add name and source here]}
\end{itemize}

\subsection{I\textsuperscript{2}C Scanner}
\label{sec:i2c_scan}

Use this sketch to verify hardware before running the full firmware:

\begin{lstlisting}[language=C++, caption={I$^2$C scanner sketch}]
#include <Wire.h>

void setup() {
  Wire.begin();
  Wire.setClock(400000);  // 400 kHz Fast Mode
  Serial.begin(115200);
  Serial.println("I2C Scanner");
}

void loop() {
  for (uint8_t addr = 1; addr < 127; addr++) {
    Wire.beginTransmission(addr);
    if (Wire.endTransmission() == 0) {
      Serial.print("Found device at 0x");
      Serial.println(addr, HEX);
    }
  }
  Serial.println("-- scan complete --");
  delay(3000);
}
\end{lstlisting}

Expected output (two boards):
\begin{lstlisting}
Found device at 0x70   <- Board 0 mux
Found device at 0x71   <- Board 1 mux
\end{lstlisting}

After confirming both muxes, scan inside each channel:

\begin{lstlisting}[language=C++, caption={Per-channel I$^2$C scan}]
void scanChannel(uint8_t muxAddr, uint8_t channel) {
  // Select channel
  Wire.beginTransmission(muxAddr);
  Wire.write(1 << channel);
  Wire.endTransmission();

  // Scan
  Wire.beginTransmission(0x30);
  if (Wire.endTransmission() == 0)
    Serial.println("  MMC5983MA found at 0x30");
  else
    Serial.println("  No sensor!");

  // Deselect
  Wire.beginTransmission(muxAddr);
  Wire.write(0x00);
  Wire.endTransmission();
}
\end{lstlisting}

\subsection{Core Firmware Structure}

\begin{lstlisting}[language=C++, caption={Firmware skeleton --- main loop}]
#include <Wire.h>
// #include <MMC5983MA.h>  // add your library here

#define MUX0  0x70
#define MUX1  0x71
#define MMC   0x30
#define RST_PIN 4   // Arduino pin connected to RST net

void selectSensor(uint8_t muxAddr, uint8_t channel) {
  Wire.beginTransmission(muxAddr);
  Wire.write(1 << channel);
  Wire.endTransmission();
}

void deselectAll(uint8_t muxAddr) {
  Wire.beginTransmission(muxAddr);
  Wire.write(0x00);
  Wire.endTransmission();
}

void resetMuxes() {
  digitalWrite(RST_PIN, LOW);
  delayMicroseconds(10);
  digitalWrite(RST_PIN, HIGH);
}

void readSensor(uint8_t muxAddr, uint8_t channel,
                float &Bx, float &By, float &Bz) {
  selectSensor(muxAddr, channel);

  // TODO: issue SET pulse, trigger measurement, read 18-bit registers
  // Convert raw counts to Gauss:
  //   B_G = (raw - 2^17) / (2^18 / 16.0)

  deselectAll(muxAddr);
}

void setup() {
  Wire.begin();
  Wire.setClock(400000);
  Serial.begin(115200);
  pinMode(RST_PIN, OUTPUT);
  digitalWrite(RST_PIN, HIGH);
  resetMuxes();
}

void loop() {
  float Bx, By, Bz;
  // Print header
  Serial.println("sensorID,Bx_G,By_G,Bz_G");

  // Board 0 (mux 0x70), sensors 0-3
  for (uint8_t ch = 0; ch < 4; ch++) {
    readSensor(MUX0, ch, Bx, By, Bz);
    Serial.print(ch); Serial.print(",");
    Serial.print(Bx,4); Serial.print(",");
    Serial.print(By,4); Serial.print(",");
    Serial.println(Bz,4);
  }

  // Board 1 (mux 0x71), sensors 4-7
  for (uint8_t ch = 0; ch < 4; ch++) {
    readSensor(MUX1, ch, Bx, By, Bz);
    Serial.print(ch+4); Serial.print(",");
    Serial.print(Bx,4); Serial.print(",");
    Serial.print(By,4); Serial.print(",");
    Serial.println(Bz,4);
  }

  delay(100);  // 10 Hz acquisition
}
\end{lstlisting}

\newpage
% ══════════════════════════════════════════════════════════════════════════════
\section{Reading and Interpreting Data}

\subsection{Output Format}

The firmware streams CSV over USB-serial at 115200 baud. Each line
represents one sensor reading:

\begin{lstlisting}
sensorID,Bx_G,By_G,Bz_G
0,0.2341,0.0123,-0.4412
1,0.2339,0.0120,-0.4410
...
7,0.2344,0.0125,-0.4415
\end{lstlisting}

Open the Arduino Serial Monitor or connect a Python script
(see Section~\ref{sec:dataworkflow}).

\subsection{Unit Conversion}

The MMC5983MA outputs 18-bit unsigned integers. The zero-field output
code is $2^{17} = 131072$. The full-scale range is $\pm8$\,G across
$2^{18} = 262144$ counts, giving a sensitivity of
$16\,\text{G} / 262144 = 0.0625$\,mG/LSB. The conversion is:

\begin{equation}
  B\,[\text{G}] = \frac{\text{raw} - 2^{17}}{2^{18}/16}
               = \frac{\text{raw} - 131072}{16384}
  \label{eq:conversion}
\end{equation}

where raw is the 18-bit output value (combined from the six measurement
registers \texttt{0x00}--\texttt{0x05}, plus two LSBs in \texttt{0x06}).

\subsection{SET/RESET Procedure}
\label{sec:setresetproc}

Issue a SET/RESET at the beginning of each acquisition session and
periodically during long runs (recommended every 5--10 minutes, or if
readings drift unexpectedly):

\begin{enumerate}
  \item Write \texttt{0x08} to \texttt{CONTROL\_0} (\texttt{0x09}) to
        issue a \textbf{SET} pulse. Wait $\geq1\,\mu$s.
  \item Take measurement $B_\text{SET}$.
  \item Write \texttt{0x10} to \texttt{CONTROL\_0} to issue a
        \textbf{RESET} pulse. Wait $\geq1\,\mu$s.
  \item Take measurement $B_\text{RESET}$.
  \item Compute $B = (B_\text{SET} - B_\text{RESET})/2$ to cancel the
        DC offset.
\end{enumerate}

For continuous monitoring where offset cancellation is less critical,
a single SET at startup followed by triggered measurements is acceptable.

\subsection{Data Collection Workflow (for Chunya)}
\label{sec:dataworkflow}

\begin{enumerate}
  \item Connect the Arduino Nano Every to the computer via USB.
  \item Open a terminal or run the Python logger script:
\begin{lstlisting}[language=Python, caption={Minimal Python logger}]
import serial, csv, time

port = "COM3"          # Windows: COMx; Linux/Mac: /dev/ttyACM0
baud = 115200

with serial.Serial(port, baud, timeout=1) as ser, \
     open("data.csv", "w", newline="") as f:
    writer = csv.writer(f)
    writer.writerow(["time_s","id","Bx","By","Bz"])
    t0 = time.time()
    while True:
        line = ser.readline().decode().strip()
        if line and not line.startswith("sensor"):
            parts = line.split(",")
            writer.writerow([round(time.time()-t0,3)] + parts)
\end{lstlisting}
  \item Allow the system to warm up for 30 seconds before recording data.
  \item Issue a SET/RESET at the start of each run (see above or
        press the reset button to re-run \texttt{setup()}).
  \item Stop logging with Ctrl-C; data is saved to \texttt{data.csv}.
  \item Verify data with \texttt{pandas}: confirm all 8 sensor IDs
        appear and field magnitudes are in the range 0.2--0.6\,G
        (ambient Earth field).
\end{enumerate}

\newpage
% ══════════════════════════════════════════════════════════════════════════════
\section{Troubleshooting}

\begin{table}[H]
  \centering
  \caption{Common Issues and Resolutions}
  \begin{tabular}{p{3.8cm} p{4.2cm} p{5cm}}
    \toprule
    \textbf{Symptom} & \textbf{Likely Cause} & \textbf{Resolution} \\
    \midrule
    I$^2$C scanner shows nothing
      & Pull-ups missing; solder joint on mux
      & Verify 2.7\,k$\Omega$ on SDA/SCL; reflow U1 \\
    \addlinespace
    Only one mux found (e.g., only \texttt{0x70})
      & Board 1 A0 not moved to VCC
      & Rework A0 solder bridge on Board 1 TCA9546A (see Section~\ref{sec:twoboard}) \\
    \addlinespace
    Mux found but sensor \texttt{0x30} missing on a channel
      & Bad reflow on that MMC5983MA; wrong channel byte
      & Re-solder suspect sensor; check channel select logic \\
    \addlinespace
    All-zeros or maxed-out readings
      & SET/RESET not issued; sensor not in I$^2$C mode (SPL\_CS floating)
      & Issue SET before measurement; verify SPL\_CS is NC not floating \\
    \addlinespace
    Noisy / drifting readings
      & Insufficient SET/RESET; ferromagnetic object nearby
      & Repeat SET/RESET; remove tools or cables from sensor vicinity \\
    \addlinespace
    FFC cable connects but no comms
      & Cable orientation wrong (not Type-B)
      & Flip cable end-for-end; re-check contact orientation \\
    \addlinespace
    Upload fails (Nano Every)
      & Wrong board/Registers Emulation setting
      & Set Registers Emulation to ``None (ATMEGA4809)''; double-tap reset \\
    \addlinespace
    LM3940 output $\neq$ 3.3\,V
      & C2 wrong polarity; U2 misorientated
      & Verify C2 ($+$ to OUT pin); check U2 pin 1 marker \\
    \bottomrule
  \end{tabular}
  \label{tab:troubleshoot}
\end{table}

\subsection{Using an Oscilloscope to Debug I\textsuperscript{2}C}

Probe SDA on pin 15 and SCL on pin 14 of U1. A healthy transaction at
400\,kHz should show:
\begin{itemize}
  \item SCL: clean square wave, 400\,kHz period, logic-high $\approx3.3\,\text{V}$.
  \item SDA: data transitions only when SCL is low; stable during SCL high.
  \item ACK: SDA pulled low by the device on the 9th clock pulse.
\end{itemize}

If SDA does not return high between transactions, suspect a stuck device.
Assert the RST pin low for $>10\,\mu$s to reset the mux and clear any
stuck state.

\subsection{Bus Recovery Procedure}

If the I$^2$C bus hangs (SDA stuck low):
\begin{enumerate}
  \item Assert RST\_PIN low from the Arduino for \SI{100}{\micro\second}.
  \item Release RST\_PIN high.
  \item Call \texttt{Wire.end()} then \texttt{Wire.begin()} in firmware to
        reinitialize the TWI peripheral.
  \item Re-run the I$^2$C scanner to confirm bus recovery.
\end{enumerate}

\newpage
% ══════════════════════════════════════════════════════════════════════════════
\section{Known Limitations and Future Work}

\begin{itemize}
  \item \textbf{No on-chip temperature compensation:} The MMC5983MA offset
        drifts with temperature. For precision measurements over long runs,
        periodically repeat the SET/RESET subtraction procedure.
  \item \textbf{No interrupt-driven acquisition:} The INT pin is unused;
        the firmware polls the measurement-done bit. A future revision
        could wire INT to an Arduino input to reduce latency and CPU load.
  \item \textbf{Expansion limited to 8 addresses (0x70--0x77):} A maximum
        of 8 boards (32 sensors) can share a single I$^2$C bus using the
        TCA9546A address range. Beyond this, a second hardware I$^2$C
        bus or a different mux topology is required.
  \item \textbf{FFC cable length sensitivity:} Long FFC cables increase
        bus capacitance. If communication errors occur with cables
        $>$30\,cm, reduce \texttt{Wire.setClock()} to 100\,kHz.
  \item \textbf{SPI mode not implemented:} The MMC5983MA supports SPI for
        faster data rates ($>$1\,MHz). If the 400\,kHz I$^2$C throughput
        proves insufficient for future experiments, a board redesign
        using SPI would allow much higher sample rates.
\end{itemize}

\newpage
% ══════════════════════════════════════════════════════════════════════════════
\section*{Acknowledgments}
\addcontentsline{toc}{section}{Acknowledgments}

Thank you to Dr.\ Elliott for guidance throughout this project, and to
Chunya Wang for testing the two-board configuration and identifying
the I$^2$C address conflict (and its solution) during system bring-up.

\newpage
% ══════════════════════════════════════════════════════════════════════════════
\begin{thebibliography}{9}

\bibitem{mmc5983ma}
  MEMSIC, \textit{MMC5983MA 3-Axis Magnetic Sensor with I$^2$C/SPI Interface
  Datasheet}, Rev.\ A.

\bibitem{tca9546a}
  Texas Instruments, \textit{TCA9546A Low-Voltage 4-Channel I$^2$C Switch
  with Reset Datasheet}, SCPS204.

\bibitem{lm3940}
  Texas Instruments, \textit{LM3940 1-A Low-Dropout Regulator for 5-V to
  3.3-V Conversion Datasheet}, SNOS386.

\bibitem{nanoevery}
  Arduino, \textit{Arduino Nano Every Datasheet and Pinout Reference},
  \url{https://docs.arduino.cc/hardware/nano-every}.

\bibitem{kicad}
  KiCad EDA, \url{https://www.kicad.org}.

\end{thebibliography}

% ══════════════════════════════════════════════════════════════════════════════
\appendix

\section{I\textsuperscript{2}C Address Map}

\begin{table}[H]
  \centering
  \caption{Complete I$^2$C Address Map (two-board system)}
  \begin{tabular}{llll}
    \toprule
    \textbf{Device} & \textbf{Address} & \textbf{Board} &
    \textbf{Notes} \\
    \midrule
    TCA9546A (U1) & \texttt{0x70} & Board 0 & A0=GND \\
    TCA9546A (U1) & \texttt{0x71} & Board 1 & A0=VCC \\
    MMC5983MA (U3--U6) & \texttt{0x30} & Both & Isolated per mux channel \\
    Arduino Nano Every & --- & --- & Master only, no slave addr \\
    \bottomrule
  \end{tabular}
  \label{tab:i2c_map}
\end{table}

\section{Register Quick Reference}

\begin{table}[H]
  \centering
  \caption{MMC5983MA Key Registers}
  \begin{tabular}{lllp{6cm}}
    \toprule
    \textbf{Reg (hex)} & \textbf{Name} & \textbf{R/W} & \textbf{Description} \\
    \midrule
    0x00 & Xout0  & R & X-axis output [17:10] \\
    0x01 & Xout1  & R & X-axis output [9:2] \\
    0x02 & Yout0  & R & Y-axis output [17:10] \\
    0x03 & Yout1  & R & Y-axis output [9:2] \\
    0x04 & Zout0  & R & Z-axis output [17:10] \\
    0x05 & Zout1  & R & Z-axis output [9:2] \\
    0x06 & XYZout2 & R & Bits [1:0] of X, Y, Z (18-bit) \\
    0x08 & Status & R & Bit 0: Meas\_M\_Done \\
    0x09 & Control\_0 & W & Bit 0: TM\_M (trigger); Bit 3: SET; Bit 4: RESET \\
    0x0A & Control\_1 & W & BW[1:0]: bandwidth / ODR select \\
    0x2F & Product ID & R & Should read \texttt{0x30} \\
    \bottomrule
  \end{tabular}
  \label{tab:registers}
\end{table}

\section{Gerber File Manifest}

All Gerber files were generated from KiCad~10.0.1 on 2026-04-27.
The job file is \texttt{MAG\_PCB\_FINAL-job.gbrjob}.

\begin{table}[H]
  \centering
  \caption{Gerber File Manifest}
  \begin{tabular}{lll}
    \toprule
    \textbf{Filename} & \textbf{Layer} & \textbf{Function} \\
    \midrule
    \texttt{MAG PCB FINAL-F\_Cu.gbr}         & F\_Cu (L1)       & Top copper, all signal routing \\
    \texttt{MAG PCB FINAL-B\_Cu.gbr}         & B\_Cu (L2)       & Bottom copper, ground/return paths \\
    \texttt{MAG PCB FINAL-F\_Paste.gbr}      & F\_Paste         & Top solder paste (stencil) \\
    \texttt{MAG PCB FINAL-B\_Paste.gbr}      & B\_Paste         & Bottom solder paste \\
    \texttt{MAG PCB FINAL-F\_Silkscreen.gbr} & F\_Silkscreen    & Top component labels and outline \\
    \texttt{MAG PCB FINAL-B\_Silkscreen.gbr} & B\_Silkscreen    & Bottom labels \\
    \texttt{MAG PCB FINAL-F\_Mask.gbr}       & F\_Mask          & Top solder mask (openings) \\
    \texttt{MAG PCB FINAL-B\_Mask.gbr}       & B\_Mask          & Bottom solder mask \\
    \texttt{MAG PCB FINAL-Edge\_Cuts.gbr}    & Edge\_Cuts       & Board outline / routed profile \\
    \texttt{MAG PCB FINAL-job.gbrjob}        & ---              & Gerber job file (fab instructions) \\
    \bottomrule
  \end{tabular}
  \label{tab:gerbers}
\end{table}

Submit all ten files to the PCB fabricator. The job file encodes the
board size (50.05\,mm $\times$ 120.05\,mm), layer count (2),
thickness (1.6\,mm), and design rules automatically.
\end{document}

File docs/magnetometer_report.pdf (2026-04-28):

# Multi-Sensor Magnetometer PCB

### Design, Operation, and Programming Reference

### Luke Hojnicki Coherent and Quantum Optics Lab Dr. Elliott, Purdue University

### April 27, 2026

Prepared for internal lab use. Intended audience: future lab members and primary user Chunya Wang.

Multi-Sensor Magnetometer PCB | Coherent & Quantum Optics Lab — Purdue ECE

## Contents

1 Introduction and Purpose | 4
2 System Architecture | 5
3 Component Descriptions | 7
4 Circuit Schematics | 12
5 PCB Layout | 15
6 Assembly and Setup | 19
7 Two-Board Setup | 21

7.1 Overview | | 21
7.2 Hardware Modification for Board 1 | | 21
7.3 FFC Cable Connection | | 21
7.4 Sensor Numbering Convention | | 21
8 Programming the Board | 23
8.1 Development Environment | | 23
8.2 I²C Scanner | | 23
8.3 Core Firmware Structure | | 24
9 Reading and Interpreting Data | 26
9.1 Output Format | | 26
9.2 Unit Conversion | | 26
9.3 SET/RESET Procedure | | 26
9.4 Data Collection Workflow (for Chunya) | | 26
10 Troubleshooting | 28
10.1 Using an Oscilloscope to Debug I²C | | 28
10.2 Bus Recovery Procedure | | 29
11 Known Limitations and Future Work | 30
Acknowledgments | 31
A I²C Address Map | 32
B Register Quick Reference | 33
C Gerber File Manifest | 33

## List of Figures

1 | Full system block diagram. The Arduino Nano Every drives two identical
sensor boards (Board 0 and Board 1) via a shared FFC bus | | 5
2 | Top-level schematic showing FFC connector, TCA9546A, and four MMC5983MA
instances (one board) | | 6
3 | Power distribution and FFC connector schematic. U2 (LM3940IMPX) con-
verts +5 V to +3.3 V (VCC). J4 is the input FFC connector; J1 passes signals
to the next board in the chain | | 12
4 | TCA9546AD I²C multiplexer schematic. All pull-ups are 2.7 kΩ to +3.3 V.
A0 straps select the board I²C address (see Table 4) | | 13
5 | MMC5983MA sensor schematics. All four instances are identical; each is
isolated on its own TCA9546A downstream channel | | 14
6 | PCB layout rendered from Gerber files. Top layer carries nearly all routing;
the bottom layer provides a partial ground plane and return paths | | 16

## List of Tables

1 | Key Components (per board) | | 7
2 | MMC5983MA Key Specifications [1] | | 7
3 | MMC5983MA Pin Assignment (this design) | | 8
4 | TCA9546A Address Strapping per Board | | 9
5 | TCA9546A Channel Select Byte | | 9
6 | FFC Connector Pinout | | 10
7 | Arduino Nano Every Key Specifications | | 11
8 | PCB Fabrication Specifications | | 15
9 | Sensor Positions Around Circular Cutout | | 17
10 | Bill of Materials (one board) | | 19
11 | Full 8-Sensor Addressing Map | | 22
12 | Common Issues and Resolutions | | 28
13 | Complete I²C Address Map (two-board system) | | 32
14 | MMC5983MA Key Registers | | 33
15 | Gerber File Manifest | | 33

## 1 Introduction and Purpose

### 1.1 Background

This document describes the design, assembly, and operation of the Magnetometer PCB developed for Dr. Elliott’s Coherent and Quantum Optics Lab at Purdue University. The board enables simultaneous, high-resolution measurement of magnetic field vectors at multiple spatial positions, which is required for Chunya Wang’s experimental work characterizing magnetic field distributions in the lab environment.

The system measures the three-dimensional magnetic field (Bx, By, Bz) at up to eight locations using MEMSIC MMC5983MA AMR sensors arranged across two identical PCBs connected in series via a flat flexible cable (FFC). Each board hosts four sensors multiplexed over a single I²C bus and is controlled by a shared Arduino Nano Every microcontroller.

### 1.2 Design Goals

Simultaneous readout of 8 MMC5983MA sensors (4 per board, 2 boards)

Single Arduino Nano Every host controller over a shared I²C bus

On-board 5 V to 3.3 V regulation; boards powered from the Arduino’s USB supply

Daisy-chain expansion via FFC connector (Top-on-One-Side / Bottom-on-the-Other cable type)

Address conflict resolution between boards via hardware address strapping on the TCA9546A multiplexer

Minimal magnetic interference from PCB-generated fields (see Section 5)

### 1.3 Scope of This Document

This document covers: (1) hardware overview and component descriptions, (2) full circuit schematics, (3) PCB layout notes, (4) assembly and setup, (5) programming the board,
(6) reading and interpreting sensor data, and (7) troubleshooting. A future student or Chunya should be able to bring the system from unpowered to collecting data using only this document.

## 2 System Architecture

### 2.1 Block Diagram

Figure 1 shows the full two-board system. The Arduino Nano Every acts as the I²C master. Both boards share the same SDA, SCL, RST, +5 V, and +3.3 V lines routed through the FFC connector. Each board contains an LM3940 voltage regulator, one TCA9546A I²C multiplexer, and four MMC5983MA sensors.

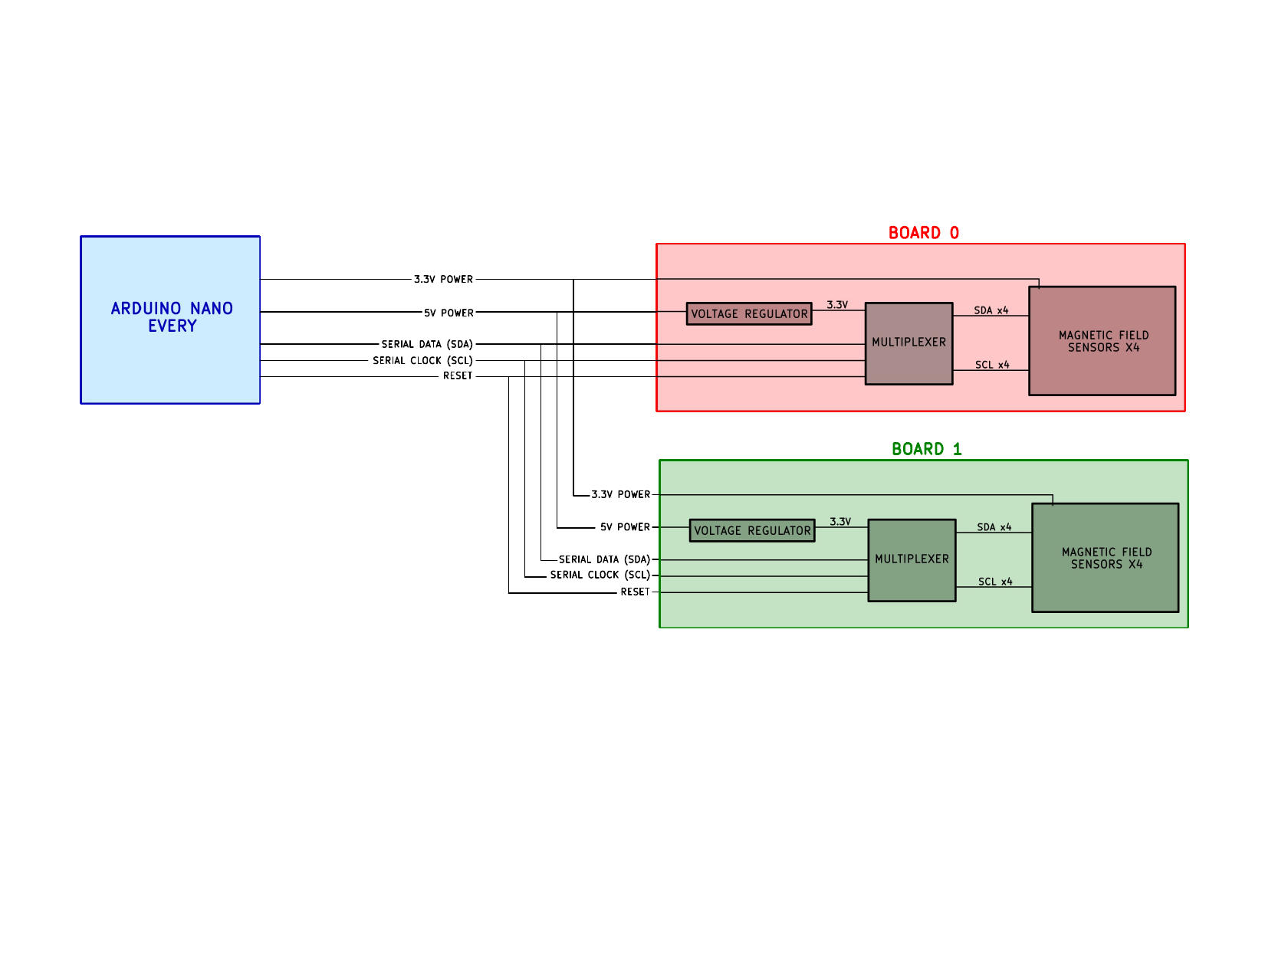
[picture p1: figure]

Figure 1: Full system block diagram. The Arduino Nano Every drives two identical sensor boards (Board 0 and Board 1) via a shared FFC bus.

### 2.2 Top-Level Schematic

Figure 2 shows the top-level KiCad schematic for one board. The FFC connector routes RST, SCL, SDA, and the four mux channel pairs (SC0/SD0 through SC3/SD3) to the TCA9546A sub-sheet and the four MMC sub-sheets. Two mounting holes (H1, H2) are also indicated.

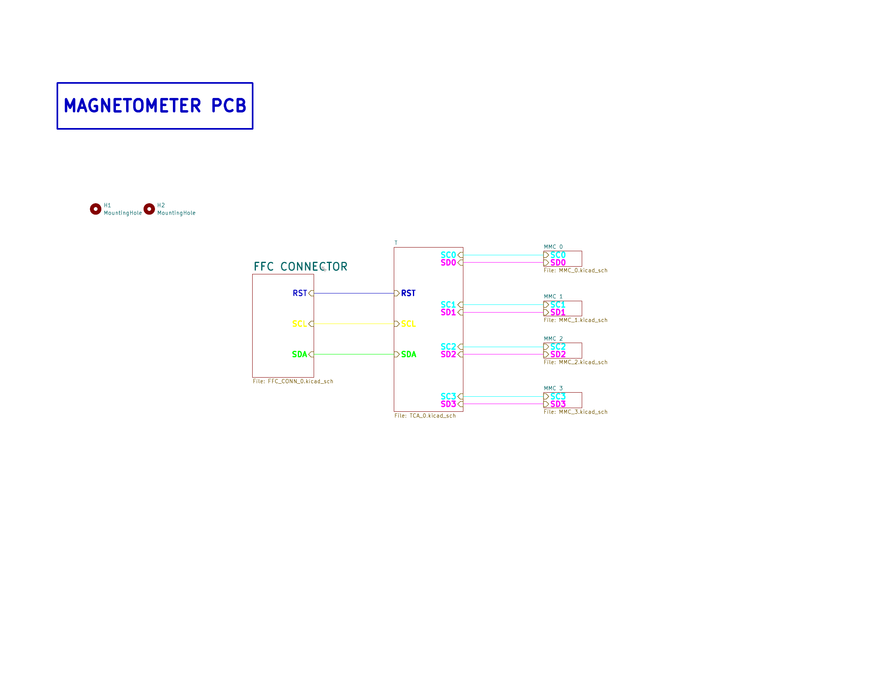
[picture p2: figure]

Figure 2: Top-level schematic showing FFC connector, TCA9546A, and four MMC5983MA instances (one board).

## 3 Component Descriptions

### 3.1 Component Summary

Table 1: Key Components (per board)

Component | Part Number Qty Function
Magnetic field sensor | MMC5983MA | 4 | 3-axis AMR magnetometer
I
2C multiplexer | TCA9546AD | 1 | 4-channel bus switch
Voltage regulator | LM3940IMPX | 1 | 5 V → 3.3 V LDO
FFC connector (in/out) [PN] | 2 | Board-to-board bus
Bulk output cap | 33 µF | 1 | LDO output decoupling
Mux bypass cap | 10 µF | 1 | TCA9546A VCC
Sensor VDD bypass cap 1 µF | 4 | MMC5983MA VDD
Sensor CAP bypass cap | 10 µF | 4 | MMC5983MA CAP pin
I
2C pull-up resistors | 2.7 kΩ | 11 | All SDA/SCL lines

### 3.2 MMC5983MA Magnetic Field Sensor

The MMC5983MA (MEMSIC) is a 3-axis anisotropic magnetoresistance (AMR) magnetic field sensor housed in a 2.0 × 2.0 × 1.0 mm LGA-16 package. It measures Bx, By, and Bz simultaneously and communicates over I²C at a single fixed address of 0x30. Key specifications are listed in Table 2.

Table 2: MMC5983MA Key Specifications [1]

Parameter | Value | Notes
Supply voltage (VDD) | 1.71–3.6 V
Full-scale range | ±8 G
Resolution (18-bit mode) 0.0625 mG/LSB | 18-bit output
RMS noise | 0.4 mG (typ.) | Continuous mode
Output data rate | up to 1000 Hz
I
2C address | 0x30 (fixed)
Operating temperature | −40 to +85 °C
Package | LGA-16, 2.0 × 2.0 mm

### 3.2.1 Pin Configuration and Connections

In this design the MMC5983MA is used exclusively in I²C mode. Table 3 lists the relevant pin assignments; SPI-only pins (SPL CS, SPL SDO) are left unconnected (NC).

Table 3: MMC5983MA Pin Assignment (this design)

Pin Name | Connected to | Notes
1 | SCL/SPL SCK SCx (from mux channel) I²C clock
2 | VDD | +3.3 V via 1 µF cap | Supply
3 | NC | —
4 | NC | —
5 | SPL CS | NC | SPI not used
6 | SPL SDO | NC | SPI not used
7–8 | NC | —
9 | GND | GND
10 | CAP | GND via 10 µF | Internal charge pump ref
11 | GND | GND
12 | NC | —
13 | VDDIO | +3.3 V | I/O voltage
14 | NC | —
15 | INT | NC | Interrupt not used
16 | SDA/SPL SDI | SDx (from mux channel) I²C data

### 3.2.2 SET/RESET Coil

The MMC5983MA contains an on-chip SET/RESET coil that drives a large current pulse through the sensing element to re-magnetize the Permalloy film in a known direction. This is necessary because:

SET magnetizes the film in the “positive” direction, establishing a known reference state and removing any negative offset from strong external field exposure.

RESET magnetizes the film in the opposite direction. Taking the difference of a SET and RESET measurement, B = (BSET − BRESET)/2, cancels the temperaturedependent bridge offset, substantially improving accuracy.

A SET or RESET pulse is issued by writing the corresponding bit in the CONTROL 0 register (0x09). The firmware must wait at least 1 µs after the pulse before issuing a measurement command. See Section 9.3 for the recommended procedure.

### 3.2.3 Fixed I²C Address and the Multiplexer Requirement

Because all MMC5983MA devices share the fixed I²C address 0x30, placing more than one sensor on a single bus causes address collisions. The TCA9546A multiplexer resolves this by isolating each sensor on its own switched bus segment, presenting only one sensor to the master at a time.

### 3.3 TCA9546A I²C Multiplexer

The TCA9546AD (Texas Instruments) is a low-voltage 4-channel I²C bus switch in a VSSOP-10 package. It sits between the Arduino Nano Every (I²C master) and the four MMC5983MA sensors, enabling the master to address each sensor individually by enabling only one downstream channel at a time.

### 3.3.1 I

2C Address Strapping

The TCA9546A I²C address is determined by the logic levels on address pins A0–A2 (pins 1, 2, 13 in the schematic). The base address is 0b1110 xxx where xxx = A2A1A0, giving the range 0x70–0x77.

On this board, A2 and A1 are tied to GND. A0 is the address differentiation pin used to distinguish Board 0 from Board 1:

Table 4: TCA9546A Address Strapping per Board

Board | A2 | A1 | A0 | I²C Address

Board 0 GND GND GND 0x70
Board 1 GND GND VCC 0x71

Important: Both boards ship with A0 tied to GND (0x70). When connecting two boards in series, the A0 pin on Board 1’s TCA9546A must be moved from GND to VCC to assign it address 0x71. This is a solder bridge or jumper change on the board. See Section 7 for the two-board setup procedure.

### 3.3.2 Channel Select Register

The TCA9546A is controlled by writing a single byte to its I²C address. Bits [3:0] enable channels 0–3 respectively; only one bit should be set at a time. Writing 0x00 disconnects all channels (recommended after each read to prevent bus contention).

Table 5: TCA9546A Channel Select Byte

Channel Byte (hex) Sensor

0 | 0x01 | U4 / MMC 0
1 | 0x02 | U3 / MMC 1
2 | 0x04 | U5 / MMC 2
3 | 0x08 | U6 / MMC 3
None | 0x00 | All disconnected

### 3.3.3 Pull-up Resistors

Each I²C segment has dedicated pull-up resistors to +3.3 V. The values used are 2.7 kΩ throughout (R1–R11), consistent with 400 kHz Fast-Mode operation at the expected bus capacitances. Specifically:

R1, R2, R3: upstream SDA, SCL, and one additional line

R4/R5, R6/R7, R8/R9, R10/R11: downstream SDA/SCL pairs for channels 0–3 (SD0/SC0 through SD3/SC3)

### 3.3.4 Bypass Capacitor

A 10 µF capacitor (C1) is placed on the TCA9546A VCC pin for bulk decoupling.

### 3.3.5 RESET Pin

The TCA9546A /RESET pin is connected to the RST net from the FFC connector, which is driven by the Arduino Nano Every. Asserting this pin low disconnects all channels and resets the channel select register to 0x00. This allows the firmware to perform a hardware bus reset without power-cycling the entire board.

### 3.4 LM3940IMPX Voltage Regulator

The LM3940IMPX (U2) is a low-dropout (LDO) linear regulator that converts the 5 V supply from the Arduino Nano Every USB rail to the 3.3 V required by the TCA9546A and MMC5983MA sensors. A 33 µF output capacitor (C2) provides output stabilization and transient suppression as specified in the LM3940 datasheet. Both GND pins of the regulator are connected to the board ground plane. Do not power the sensor VDD from the Arduino’s 5 V pin directly.

### 3.5 FFC Connector and Daisy-Chain Bus

Each board has two FFC connectors (J4 PIN IN, J1 PIN OUT) for daisy-chain expansion. The 16-pin connector carries the following signals:

Table 6: FFC Connector Pinout

Pin(s) | Signal Notes
1, 2, 15, 16 | GND | Ground
3 | +5V | Arduino USB rail
7 | SCL | I²C clock (shared bus)
10 | SDA | I²C data (shared bus)
12 | RST | Active-low mux reset
14 | +3.3V | Regulated output from LM3940
4–6, 8–9, 11, 13 NC | Not connected

Cable orientation note: The FFC cable used in this system is of the “Top-on-One-Side, Bottom-on-the-Other” (Type B) variety. This means the contacts on one end face up and the contacts on the other end face down. Ensure the cable is inserted into each connector in the correct orientation to avoid a pin-reversal short. When connecting Board 0 PIN OUT to Board 1 PIN IN, verify that power and signal nets align before applying power.

### 3.6 Arduino Nano Every

The Arduino Nano Every serves as the I²C master and USB-serial interface. It is based on the ATmega4809 microcontroller, operates at 20 MHz, and provides 3.3 V-compatible I/O.

Table 7: Arduino Nano Every Key Specifications

Parameter Value

Microcontroller ATmega4809
CPU speed | 20 MHz
Flash / SRAM | 48 kB / 6 kB
I
2C pins | A4 (SDA), A5 (SCL)
I
2C speed | Standard (100 kHz) / Fast (400 kHz)
USB interface | USB CDC via SAMD11 co-processor

The Nano Every’s A4/A5 pins connect to the shared SDA/SCL bus. A digital output pin connects to the RST net for hardware mux resets. The board is powered from USB; the on-board 3.3 V regulator output is also forwarded to the sensor boards via the FFC connector.

Upload instructions: select Arduino Nano Every under Tools → Board → Arduino megaAVR Boards, set Registers Emulation to None (ATMEGA4809), select the correct COM port, and click Upload.

## 4 Circuit Schematics

### 4.1 Power Distribution

Figure 3 shows the power and connector schematic. The LM3940IMPX (U2) receives +5 V from the FFC connector (J4 PIN IN, pin 3) and outputs +3.3 V (VCC net) stabilized by a 33 µF capacitor (C2). The regulated +3.3 V is also forwarded to the PIN OUT connector (J1) so that it is available to downstream boards in the daisy chain. SCL, SDA, RST, and GND are passed through both connectors unchanged.

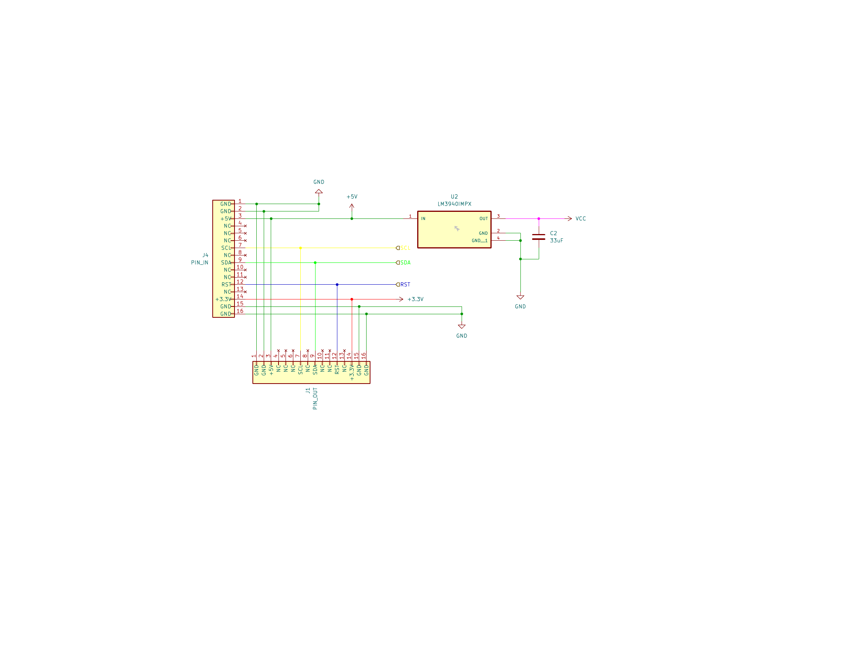
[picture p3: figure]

Figure 3: Power distribution and FFC connector schematic. U2 (LM3940IMPX) converts +5 V to +3.3 V (VCC). J4 is the input FFC connector; J1 passes signals to the next board in the chain.

### 4.2 I

### 2C Multiplexer (TCA9546A)

Figure 4 shows the TCA9546A multiplexer schematic. The upstream SDA and SCL lines from the FFC connector enter pins 15 and 14 of U1 respectively, with 2.7 kΩ pull-ups (R1– R3) to VCC. Each of the four downstream channel pairs (SD0/SC0 through SD3/SC3) has its own 2.7 kΩ pull-up pair to +3.3 V (R4–R11). Address pins A2 and A1 (pins 13 and 2) are tied to GND; A0 (pin 1) determines the board address (GND = 0x70, VCC = 0x71). The RESET pin (pin 3) is driven by the RST net from the FFC connector.

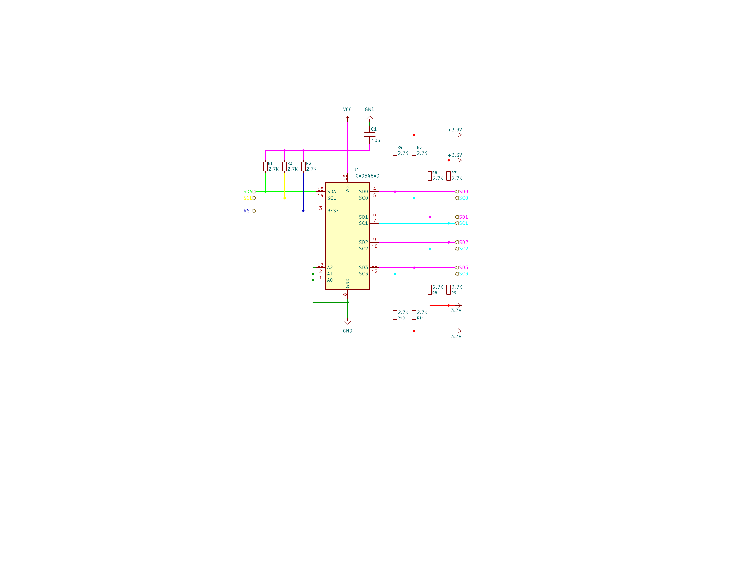
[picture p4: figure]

Figure 4: TCA9546AD I²C multiplexer schematic. All pull-ups are 2.7 kΩ to +3.3 V. A0 straps select the board I²C address (see Table 4).

### 4.3 MMC5983MA Sensor Instances

All four sensors per board are identical circuits; they differ only in which mux channel they connect to (SC0/SD0 through SC3/SD3). Each sensor has: a 1 µF bypass capacitor on VDD (pins C5, C3, C7, C9 for sensors 0–3) and a 10 µF capacitor on the CAP pin (C6, C4, C8, C10) to GND, as required by the MMC5983MA datasheet. SPL CS and SPL SDO are left unconnected to select I²C mode. The INT pin is not connected as interrupt- driven acquisition is not used in this implementation.

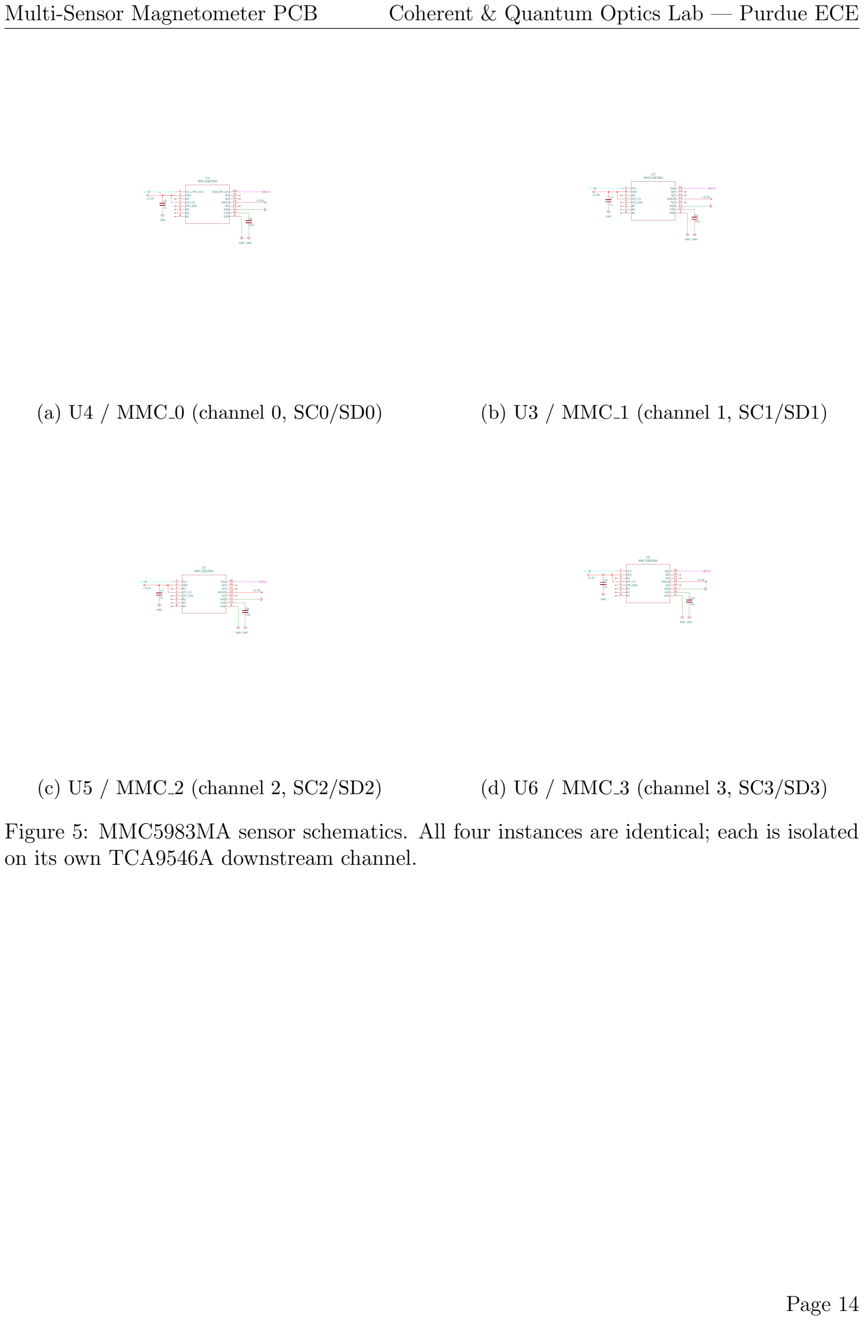
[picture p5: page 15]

(a) U4 / MMC 0 (channel 0, SC0/SD0) | (b) U3 / MMC 1 (channel 1, SC1/SD1)
(c) U5 / MMC 2 (channel 2, SC2/SD2) | (d) U6 / MMC 3 (channel 3, SC3/SD3)

Figure 5: MMC5983MA sensor schematics. All four instances are identical; each is isolated on its own TCA9546A downstream channel.

## 5 PCB Layout

### 5.1 Board Overview

The PCB measures 50.05 mm × 120.05 mm and uses a 2-layer stackup (F Cu / B Cu) on a standard 1.6 mm FR4 substrate. It was designed in KiCad 10.0.1. The board outline has a distinctive hourglass profile: a wider octagonal control section at the top, a narrow routing neck in the middle, and a wider octagonal sensor section at the bottom with a large circular cutout at its center.

Table 8: PCB Fabrication Specifications

Parameter | Value
Board dimensions | 50.05 mm × 120.05 mm
Layer count | 2 (F Cu top, B Cu bottom)
Board thickness | 1.6 mm
Min trace width | 0.3 mm
Pad-to-pad clearance | 0.2 mm
Pad-to-track clearance 0.2 mm
Surface finish | [HASL / ENIG / specify]

### 5.2 Top and Bottom Copper Layers

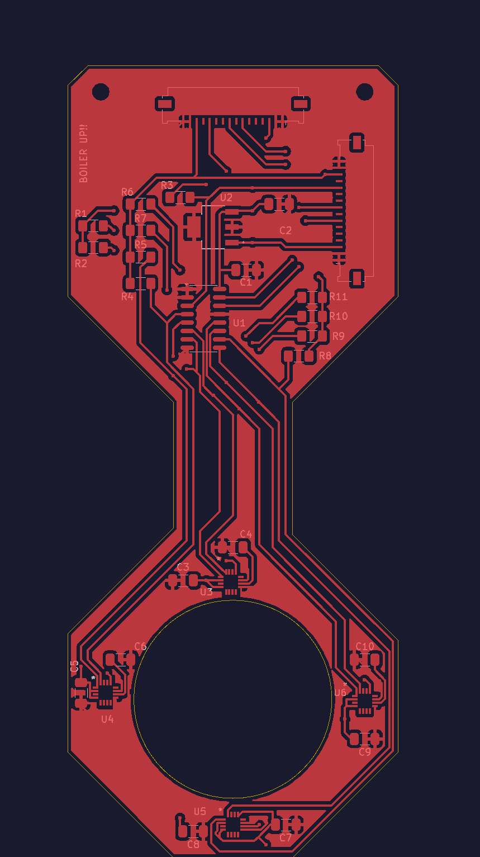
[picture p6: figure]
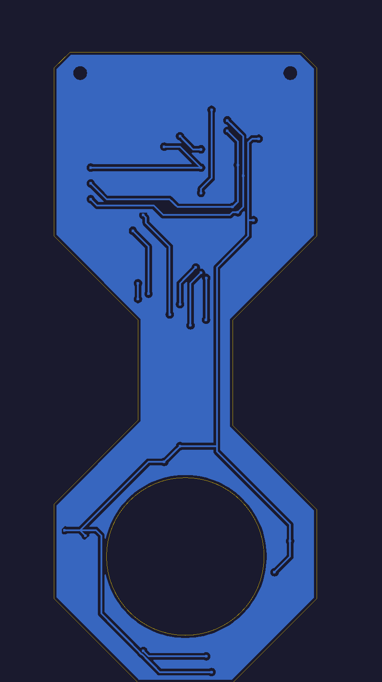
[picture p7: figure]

(a) Top copper (F Cu, red) with silkscreen. | (b) Bottom copper (B Cu, blue).

Figure 6: PCB layout rendered from Gerber files. Top layer carries nearly all routing; the bottom layer provides a partial ground plane and return paths.

### 5.3 Board Shape and Functional Regions

The board is divided into three functional regions:

1. Control section (top octagon): Houses the two FFC connectors, the LM3940IMPX regulator (U2) with its 33 µF output cap (C2), the TCA9546A multiplexer (U1) with its 10 µF bypass cap (C1), and all 11 pull-up resistors (R1–R11). Two mounting holes are located at the top corners of this section.
2. Routing neck (center): A narrow bridge carrying the eight I²C channel traces (SD0–SD3, SC0–SC3) from the multiplexer to the sensor section. Keeping these traces confined to the neck minimizes the copper area in the magnetically sensitive sensor

region.

3. Sensor section (bottom octagon): Contains the four MMC5983MA sensors (U3– U6) and their associated bypass capacitors (C3–C10), arranged around a large circular cutout (approximately 30 mm radius / 60 mm diameter). The cutout allows the board to be mounted concentrically around a cylindrical experimental object such as a glass cell or optical tube.

### 5.4 Sensor Placement Around the Circular Cutout

The four sensors are positioned at the cardinal points of the circular cutout to provide spatially distributed field measurements around the mounted object:

Table 9: Sensor Positions Around Circular Cutout

Ref. Channel | Clock position | Notes
U3 | 1 (SC1/SD1) 12 o’clock (top)
U4 | 0 (SC0/SD0) 9 o’clock (left)
U6 | 3 (SC3/SD3) 3 o’clock (right)
U5 | 2 (SC2/SD2) 6 o’clock (bottom)

Each sensor is oriented with its package aligned to the board axes. If absolute field direction relative to the mounted object is required, the orientation of each sensor’s X, Y , Z axes relative to the board frame should be recorded when installing the board in the experimental apparatus.

### 5.5 Magnetic Noise Minimization

The following layout decisions were made to minimize PCB-generated magnetic interference at the sensor locations:

Functional isolation: All active components that carry significant current (regulator, mux, connectors) are confined to the control section, physically separated from the sensors by the narrow neck. This puts the largest current loops as far as possible from the sensor LGAs.

Bypass cap proximity: Each sensor’s 1 µF VDD cap and 10 µF CAP pin cap are placed immediately adjacent to the sensor pads, minimizing the loop area of highfrequency switching currents.

No ferromagnetics near sensors: All passive components in the sensor section are ceramic capacitors; no inductors or ferrite-core components are placed in the bottom octagon.

Trace routing in neck: The I²C channel traces are bundled tightly through the neck and routed as differential-pair-like groups (SDA/SCL per channel adjacent) to reduce loop area and radiated field.

Silkscreen note: The board carries a “BOILER UP!!” silkscreen label on the control section — this is cosmetic only and has no electrical significance.

## 6 Assembly and Setup

### 6.1 Bill of Materials (BOM)

Table 10: Bill of Materials (one board)

Ref. | Value / PN | Qty Function | Supplier
U1 | TCA9546AD | 1 | I²C mux | [TI / Digikey]
U2 | LM3940IMPX | 1 | 5V→3.3V LDO | [TI / Digikey]
U3–U6 | MMC5983MA | 4 | 3-axis sensor | [MEMSIC / Digikey]
J1, J4 | FFC 16-pin | 2 | Board connector | [PN]
C1 | 10 µF | 1 | TCA VCC bypass | [PN]
C2 | 33 µF | 1 | LDO output cap | [PN]
C3, C5, C7, C9 | 1 µF | 4 | Sensor VDD bypass [PN]
C4, C6, C8, C10 10 µF | 4 | Sensor CAP pin | [PN]
R1–R11 | 2.7 kΩ | 11 | I²C pull-ups | [PN]
H1, H2 | Mounting hole 2 | Mechanical | —

### 6.2 Soldering Notes

The MMC5983MA and TCA9546AD are LGA/VSSOP packages that require reflow soldering. Hand-soldering is possible for the VSSOP but not recommended for the LGA sensors.

Apply flux generously under LGA pads before placing components.

After reflow, inspect all sensor and mux connections with a microscope or loupe. Tombstoned or bridged pads will cause I²C failures.

The LM3940IMPX is a through-hole or SMD package (verify footprint); solder last to avoid heat damage to nearby sensors.

### 6.3 Initial Power-On Checklist

1. Before connecting the Arduino: Measure the +3.3 V output of U2 with a DMM. It should read 3.3 V ± 0.1 V. If it reads 0 V or 5 V, check U2 orientation and C2 polarity.
2. Verify that SDA and SCL have 3.3 V pull-ups by measuring them at rest (should read ≈ 3.3 V with no activity).
3. Connect the Arduino and upload the I²C scanner sketch (Section 8.2).
4. Confirm that 0x70 (Board 0 mux) appears in the scan. If running two boards, also confirm 0x71 (Board 1 mux).
5. Select each mux channel in turn and verify that 0x30 (MMC5983MA) appears on each channel. Eight total hits expected for the two-board system.

6. Run the test firmware and confirm plausible field readings (±ambient Earth field, roughly 0.2–0.6 G depending on orientation).

## 7 Two-Board Setup

### 7.1 Overview

Two identical boards are connected in series via an FFC cable to provide eight sensor channels total. The Arduino Nano Every drives both boards over the same SDA, SCL, RST, and power lines. The two TCA9546A multiplexers are differentiated by I²C address:

Board 0: Mux address 0x70 (A0 = GND, factory default)

Board 1: Mux address 0x71 (A0 = VCC, requires hardware modification)

### 7.2 Hardware Modification for Board 1

On Board 1’s TCA9546A (U1), the A0 pin must be changed from GND to VCC:

1. Identify the A0 pad on U1 (pin 1 of TCA9546AD; see Figure 4).
2. Remove or cut the GND connection to A0.
3. Bridge A0 to the VCC net (3.3 V). A short wire or solder bridge to the adjacent VCC pad is sufficient.
4. After the modification, confirm with an ohmmeter that A0 is connected to VCC and isolated from GND.

### 7.3 FFC Cable Connection

1. Use a Type-B FFC cable (Top-on-One-Side, Bottom-on-the-Other). This type is required because the PIN OUT connector on one board faces opposite to the PIN IN connector on the next.
2. Insert one end of the cable into Board 0’s PIN OUT connector (J1). The contacts should face the correct direction for the ZIF/LIF latch on that connector.
3. Insert the other end into Board 1’s PIN IN connector (J4).
4. Before powering on: double-check that the +5 V, +3.3 V, GND, SDA, and SCL pins map correctly across the connector. A pin reversal will short power to GND.

### 7.4 Sensor Numbering Convention

With both boards connected, the eight sensors are addressed as follows:

Table 11: Full 8-Sensor Addressing Map

Logical ID Board | Mux addr Channel Sensor I²C addr
Sensor 0 | Board 0 0x70 | 0 (0x01) | 0x30
Sensor 1 | Board 0 0x70 | 1 (0x02) | 0x30
Sensor 2 | Board 0 0x70 | 2 (0x04) | 0x30
Sensor 3 | Board 0 0x70 | 3 (0x08) | 0x30
Sensor 4 | Board 1 0x71 | 0 (0x01) | 0x30
Sensor 5 | Board 1 0x71 | 1 (0x02) | 0x30
Sensor 6 | Board 1 0x71 | 2 (0x04) | 0x30
Sensor 7 | Board 1 0x71 | 3 (0x08) | 0x30

## 8 Programming the Board

### 8.1 Development Environment

Arduino IDE 2.x (or 1.8.x)

Board package: Arduino megaAVR Boards (install via Boards Manager, search “megaAVR”)

Required libraries: Wire (built-in), [MMC5983MA library — add name and source here]

### 8.2 I

### 2C Scanner

Use this sketch to verify hardware before running the full firmware:

1 # include < Wire .h >

2
3 | void setup () {
4 | Wire . begin () ;
5 | Wire . setClock (400000) ; | // 400 kHz Fast Mode
6 | Serial . begin (115200) ;
7 | Serial . println ("I2C ␣ Scanner ") ;
8 | }

9
10 | void loop () {
11 | for ( uint8_t addr = 1; addr < 127; addr ++) {
12 | Wire . beginTransmission ( addr ) ;
13 | if ( Wire . endTransmission () == 0) {
14 | Serial . print (" Found ␣ device ␣at␣0x") ;
15 | Serial . println ( addr , HEX ) ;
16 | }
17 | }
18 | Serial . println (" --␣ scan ␣ complete ␣ --") ;
19 | delay (3000) ;
20 | }

Listing 1: I²C scanner sketch

Expected output (two boards):

1 | Found device at 0 x70 | <- Board 0 mux
2 | Found device at 0 x71 | <- Board 1 mux

After confirming both muxes, scan inside each channel:

1 | void scanChannel ( uint8_t muxAddr , uint8_t channel ) {
2 | // Select channel
3 | Wire . beginTransmission ( muxAddr ) ;
4 | Wire . write (1 << channel ) ;

5 Wire . endTransmission () ;

6
7 | // Scan
8 | Wire . beginTransmission (0 x30 ) ;
9 | if ( Wire . endTransmission () == 0)
10 | Serial . println ("␣␣ MMC5983MA ␣ found ␣at␣0x30 ") ;
11 | else
12 | Serial . println ("␣␣No␣ sensor !") ;

13
14 | // Deselect
15 | Wire . beginTransmission ( muxAddr ) ;
16 | Wire . write (0 x00 ) ;
17 | Wire . endTransmission () ;
18 | }

Listing 2: Per-channel I²C scan

### 8.3 Core Firmware Structure

1 | # include < Wire .h >
2 | // # include <MMC5983MA .h> | // add your library here

3
4 | # define MUX0 | 0 x70
5 | # define MUX1 | 0 x71
6 | # define MMC | 0 x30
7 | # define RST_PIN 4 | // Arduino pin connected to RST net

8
9 | void selectSensor ( uint8_t muxAddr , uint8_t channel ) {
10 | Wire . beginTransmission ( muxAddr ) ;
11 | Wire . write (1 << channel ) ;
12 | Wire . endTransmission () ;
13 | }

14
15 | void deselectAll ( uint8_t muxAddr ) {
16 | Wire . beginTransmission ( muxAddr ) ;
17 | Wire . write (0 x00 ) ;
18 | Wire . endTransmission () ;
19 | }

20
21 | void resetMuxes () {
22 | digitalWrite ( RST_PIN , LOW ) ;
23 | delayMicroseconds (10) ;
24 | digitalWrite ( RST_PIN , HIGH ) ;
25 | }

26
27 | void readSensor ( uint8_t muxAddr , uint8_t channel ,
28 | float & Bx , float & By , float & Bz ) {
29 | selectSensor ( muxAddr , channel ) ;

30
31 // TODO : issue SET pulse , trigger measurement , read 18 - bit registers
32 | // Convert raw counts to Gauss :
33 | // | B_G = (raw - 2^17) / (2^18 / 16.0)

34
35 | deselectAll ( muxAddr ) ;
36 | }

37
38 | void setup () {
39 | Wire . begin () ;
40 | Wire . setClock (400000) ;
41 | Serial . begin (115200) ;
42 | pinMode ( RST_PIN , OUTPUT ) ;
43 | digitalWrite ( RST_PIN , HIGH ) ;
44 | resetMuxes () ;
45 | }

46
47 | void loop () {
48 | float Bx , By , Bz ;
49 | // Print header
50 | Serial . println (" sensorID ,Bx_G ,By_G , Bz_G ") ;

51
52 | // Board 0 (mux 0x70 ), sensors 0 -3
53 | for ( uint8_t ch = 0; ch < 4; ch ++) {
54 | readSensor ( MUX0 , ch , Bx , By , Bz ) ;
55 | Serial . print ( ch ) ; Serial . print (",") ;
56 | Serial . print ( Bx ,4) ; Serial . print (",") ;
57 | Serial . print ( By ,4) ; Serial . print (",") ;
58 | Serial . println ( Bz ,4) ;
59 | }

60
61 | // Board 1 (mux 0x71 ), sensors 4 -7
62 | for ( uint8_t ch = 0; ch < 4; ch ++) {
63 | readSensor ( MUX1 , ch , Bx , By , Bz ) ;
64 | Serial . print ( ch +4) ; Serial . print (",") ;
65 | Serial . print ( Bx ,4) ; Serial . print (",") ;
66 | Serial . print ( By ,4) ; Serial . print (",") ;
67 | Serial . println ( Bz ,4) ;
68 | }

69
70 | delay (100) ; | // 10 Hz acquisition
71 | }

Listing 3: Firmware skeleton — main loop

## 9 Reading and Interpreting Data

### 9.1 Output Format

The firmware streams CSV over USB-serial at 115200 baud. Each line represents one sensor reading:

1 | sensorID , Bx_G , By_G , Bz_G
2 | 0 ,0.2341 ,0.0123 , -0.4412
3 | 1 ,0.2339 ,0.0120 , -0.4410
4 | ...
5 | 7 ,0.2344 ,0.0125 , -0.4415

Open the Arduino Serial Monitor or connect a Python script (see Section 9.4).

### 9.2 Unit Conversion

The MMC5983MA outputs 18-bit unsigned integers. The zero-field output code is 2¹⁷ = 131072. The full-scale range is ±8 G across 2¹⁸ = 262144 counts, giving a sensitivity of 16 G/262144 = 0.0625 mG/LSB. The conversion is:

B [G] = raw − 2

17
2

18/16

=

raw − 131072
16384

(1)

where raw is the 18-bit output value (combined from the six measurement registers 0x00– 0x05, plus two LSBs in 0x06).

### 9.3 SET/RESET Procedure

Issue a SET/RESET at the beginning of each acquisition session and periodically during long runs (recommended every 5–10 minutes, or if readings drift unexpectedly):

1. Write 0x08 to CONTROL 0 (0x09) to issue a SET pulse. Wait ≥ 1 µs.
2. Take measurement BSET.
3. Write 0x10 to CONTROL 0 to issue a RESET pulse. Wait ≥ 1 µs.
4. Take measurement BRESET.
5. Compute B = (BSET − BRESET)/2 to cancel the DC offset.

For continuous monitoring where offset cancellation is less critical, a single SET at startup followed by triggered measurements is acceptable.

### 9.4 Data Collection Workflow (for Chunya)

1. Connect the Arduino Nano Every to the computer via USB.

2. Open a terminal or run the Python logger script:

import serial , csv , time

3 | port = " COM3 " | # Windows : COMx ; Linux /Mac : /dev / ttyACM0
| baud = 115200

with serial . Serial ( port , baud , timeout =1) as ser , \
open (" data .csv ", "w", newline ="") as f :
writer = csv . writer ( f )
writer . writerow ([" time_s ","id","Bx","By","Bz"])
| t0 = time . time ()
| while True :
line = ser . readline () . decode () . strip ()
if line and not line . startswith (" sensor ") :
parts = line . split (",")
writer . writerow ([ round ( time . time () -t0 ,3) ] + parts )

Listing 4: Minimal Python logger

3. Allow the system to warm up for 30 seconds before recording data.
4. Issue a SET/RESET at the start of each run (see above or press the reset button to re-run setup()).
5. Stop logging with Ctrl-C; data is saved to data.csv.
6. Verify data with pandas: confirm all 8 sensor IDs appear and field magnitudes are in the range 0.2–0.6 G (ambient Earth field).

## 10 Troubleshooting

Table 12: Common Issues and Resolutions

Symptom | Likely Cause | Resolution

I

2C scanner shows nothing | Pull-ups missing; sol- der joint on mux | Verify 2.7 kΩ on SDA/SCL; reflow U1
Only one mux found (e.g., only 0x70) | Board 1 A0 not moved to VCC | Rework A0 solder bridge on Board 1 TCA9546A (see Section 7)
Mux found but sen- sor 0x30 missing on a channel | Bad reflow on that MMC5983MA; wrong channel byte | Re-solder suspect sensor; check channel select logic
All-zeros or maxed- out readings | SET/RESET not is- sued; sensor not in I²C mode (SPL CS float- ing) | Issue SET before measure- ment; verify SPL CS is NC not floating

Noisy / drifting readings

Insufficient | SET/RE-
SET; | ferromagnetic
| object nearby | Repeat SET/RESET; re- move tools or cables from sensor vicinity

FFC cable connects
but no comms
Cable | orientation
| wrong (not Type-B) | Flip cable end-for-end; re- check contact orientation
Upload fails (Nano Every) | Wrong board/Registers Emulation setting | Set Registers Emulation to
“None | (ATMEGA4809)”;
| | double-tap reset
LM3940 output ̸= 3.3 V | C2 wrong polarity; U2 misorientated | Verify C2 (+ to OUT pin); check U2 pin 1 marker

### 10.1 Using an Oscilloscope to Debug I²C

Probe SDA on pin 15 and SCL on pin 14 of U1. A healthy transaction at 400 kHz should show:

SCL: clean square wave, 400 kHz period, logic-high ≈ 3.3 V.

SDA: data transitions only when SCL is low; stable during SCL high.

ACK: SDA pulled low by the device on the 9th clock pulse.

If SDA does not return high between transactions, suspect a stuck device. Assert the RST pin low for > 10 µs to reset the mux and clear any stuck state.

### 10.2 Bus Recovery Procedure

If the I²C bus hangs (SDA stuck low):

1. Assert RST PIN low from the Arduino for 100 µs.
2. Release RST PIN high.
3. Call Wire.end() then Wire.begin() in firmware to reinitialize the TWI peripheral.
4. Re-run the I²C scanner to confirm bus recovery.

## 11 Known Limitations and Future Work

No on-chip temperature compensation: The MMC5983MA offset drifts with temperature. For precision measurements over long runs, periodically repeat the SET/RE-SET subtraction procedure.

No interrupt-driven acquisition: The INT pin is unused; the firmware polls the measurement-done bit. A future revision could wire INT to an Arduino input to reduce latency and CPU load.

Expansion limited to 8 addresses (0x70–0x77): A maximum of 8 boards (32 sensors) can share a single I²C bus using the TCA9546A address range. Beyond this, a second hardware I²C bus or a different mux topology is required.

FFC cable length sensitivity: Long FFC cables increase bus capacitance. If communication errors occur with cables >30 cm, reduce Wire.setClock() to 100 kHz.

SPI mode not implemented: The MMC5983MA supports SPI for faster data rates (>1 MHz). If the 400 kHz I²C throughput proves insufficient for future experiments, a board redesign using SPI would allow much higher sample rates.

## Acknowledgments

Thank you to Dr. Elliott for guidance throughout this project, and to Chunya Wang for testing the two-board configuration and identifying the I²C address conflict (and its solution) during system bring-up.

## References

[1] MEMSIC, MMC5983MA 3-Axis Magnetic Sensor with I²C/SPI Interface Datasheet, Rev. A.
[2] Texas Instruments, TCA9546A Low-Voltage 4-Channel I²C Switch with Reset Datasheet, SCPS204.
[3] Texas Instruments, LM3940 1-A Low-Dropout Regulator for 5-V to 3.3-V Conversion Datasheet, SNOS386.
[4] Arduino, Arduino Nano Every Datasheet and Pinout Reference, https://docs.arduino.cc/hardware/nano-every. (https://docs.arduino.cc/hardware/nano-every)
[5] KiCad EDA, https://www.kicad.org.

A I

## 2C Address Map

Table 13: Complete I²C Address Map (two-board system)

Device | Address Board | Notes
TCA9546A (U1) | 0x70 | Board 0 A0=GND
TCA9546A (U1) | 0x71 | Board 1 A0=VCC
MMC5983MA (U3–U6) 0x30 | Both | Isolated per mux channel
Arduino Nano Every | — | — | Master only, no slave addr

## B Register Quick Reference

Table 14: MMC5983MA Key Registers

Reg (hex) Name | R/W Description
0x00 | Xout0 | R | X-axis output [17:10]
0x01 | Xout1 | R | X-axis output [9:2]
0x02 | Yout0 | R | Y-axis output [17:10]
0x03 | Yout1 | R | Y-axis output [9:2]
0x04 | Zout0 | R | Z-axis output [17:10]
0x05 | Zout1 | R | Z-axis output [9:2]
0x06 | XYZout2 | R | Bits [1:0] of X, Y, Z (18-bit)
0x08 | Status | R | Bit 0: Meas M Done
0x09 | Control 0 | W | Bit 0: TM M (trigger); Bit 3:
| | | SET; Bit 4: RESET
0x0A | Control 1 | W | BW[1:0]: bandwidth / ODR se-
| | | lect
0x2F | Product ID R | Should read 0x30

## C Gerber File Manifest

All Gerber files were generated from KiCad 10.0.1 on 2026-04-27. The job file is MAG PCB FINAL-job.gbrjob.

Table 15: Gerber File Manifest

Filename | | Layer | Function
MAG PCB FINAL-F Cu.gbr | F Cu (L1) | Top copper, all signal routing
MAG PCB FINAL-B Cu.gbr | B Cu (L2) | Bottom copper, ground/return paths
MAG PCB FINAL-F Paste.gbr | F Paste | Top solder paste (stencil)
MAG PCB FINAL-B Paste.gbr | B Paste | Bottom solder paste
MAG PCB FINAL-F Silkscreen.gbr | F Silkscreen Top component labels and outline
MAG PCB FINAL-B Silkscreen.gbr | B Silkscreen Bottom labels
MAG PCB FINAL-F Mask.gbr | F Mask | Top solder mask (openings)
MAG PCB FINAL-B Mask.gbr | B Mask | Bottom solder mask
MAG PCB FINAL-Edge Cuts.gbr | Edge Cuts | Board outline / routed profile
MAG PCB FINAL-job.gbrjob | — | Gerber job file (fab instructions)

Submit all ten files to the PCB fabricator. The job file encodes the board size (50.05 mm × 120.05 mm), layer count (2), thickness (1.6 mm), and design rules automatically.

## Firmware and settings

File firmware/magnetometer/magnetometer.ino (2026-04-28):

/*
 * magnetometer.ino
 *
 * Multi-sensor magnetometer firmware for the MAG PCB FINAL board.
 * Reads all 8 MMC5983MA sensors (4 per board, 2 boards) via two
 * TCA9546A I2C multiplexers and streams CSV over USB-serial at 115200 baud.
 *
 * Hardware:
 *   Arduino Nano Every (ATmega4809)
 *   Board 0: TCA9546A @ 0x70, sensors 0-3
 *   Board 1: TCA9546A @ 0x71, sensors 4-7
 *
 * Board settings (Arduino IDE):
 *   Board:                Arduino Nano Every
 *   Registers Emulation:  None (ATMEGA4809)
 *   Baud:                 115200
 */

#include <Wire.h>
#include "mmc5983ma.h"

// ── Configuration ──────────────────────────────────────────────────────────
#define MUX0_ADDR   0x70        // Board 0: A0=GND
#define MUX1_ADDR   0x71        // Board 1: A0=VCC (requires A0 rework)
#define RST_PIN     4           // Arduino GPIO → RST net on FFC connector
#define I2C_SPEED   400000UL    // 400 kHz Fast Mode
#define LOOP_DELAY_MS 100       // ~10 Hz per full 8-sensor sweep

// Set to true to use SET/RESET offset cancellation on every reading.
// More accurate but takes ~2x as long per sensor.
#define USE_OFFSET_CANCEL  false

// ── Globals ────────────────────────────────────────────────────────────────
MMC5983MA sensor;

// ── Mux helpers ───────────────────────────────────────────────────────────

void selectChannel(uint8_t muxAddr, uint8_t channel) {
    Wire.beginTransmission(muxAddr);
    Wire.write((uint8_t)(1 << channel));
    Wire.endTransmission();
}

void deselectAll(uint8_t muxAddr) {
    Wire.beginTransmission(muxAddr);
    Wire.write((uint8_t)0x00);
    Wire.endTransmission();
}

void resetMuxes() {
    digitalWrite(RST_PIN, LOW);
    delayMicroseconds(100);
    digitalWrite(RST_PIN, HIGH);
    delay(1);
}

// ── I2C scanner (for bring-up / debug) ────────────────────────────────────

void i2cScan() {
    Serial.println("# I2C scan:");
    for (uint8_t addr = 1; addr < 127; addr++) {
        Wire.beginTransmission(addr);
        if (Wire.endTransmission() == 0) {
            Serial.print("#   0x");
            Serial.println(addr, HEX);
        }
    }
    Serial.println("# Scan complete.");
}

void scanMuxChannels(uint8_t muxAddr) {
    Serial.print("# Scanning mux 0x");
    Serial.println(muxAddr, HEX);
    for (uint8_t ch = 0; ch < 4; ch++) {
        selectChannel(muxAddr, ch);
        Wire.beginTransmission(MMC5983MA_ADDR);
        uint8_t err = Wire.endTransmission();
        Serial.print("#   ch");
        Serial.print(ch);
        Serial.print(": MMC5983MA @ 0x30 -> ");
        Serial.println(err == 0 ? "OK" : "NOT FOUND");
        deselectAll(muxAddr);
    }
}

// ── Read one sensor ────────────────────────────────────────────────────────

bool readSensor(uint8_t muxAddr, uint8_t channel,
                float &Bx, float &By, float &Bz) {
    selectChannel(muxAddr, channel);
    bool ok;
    if (USE_OFFSET_CANCEL) {
        ok = sensor.readWithOffsetCancel(Bx, By, Bz);
    } else {
        uint32_t rx, ry, rz;
        ok = sensor.readRaw(rx, ry, rz);
        if (ok) {
            Bx = MMC5983MA::rawToGauss(rx);
            By = MMC5983MA::rawToGauss(ry);
            Bz = MMC5983MA::rawToGauss(rz);
        }
    }
    deselectAll(muxAddr);
    return ok;
}

// ── Setup ──────────────────────────────────────────────────────────────────

void setup() {
    Serial.begin(115200);
    while (!Serial) {}

    pinMode(RST_PIN, OUTPUT);
    digitalWrite(RST_PIN, HIGH);

    Wire.begin();
    Wire.setClock(I2C_SPEED);

    resetMuxes();
    delay(10);

    // Bring-up diagnostics — comment out after validation
    i2cScan();
    scanMuxChannels(MUX0_ADDR);
    scanMuxChannels(MUX1_ADDR);

    // Issue SET on all 8 sensors at startup
    for (uint8_t ch = 0; ch < 4; ch++) {
        selectChannel(MUX0_ADDR, ch);
        sensor.doSet();
        deselectAll(MUX0_ADDR);

        selectChannel(MUX1_ADDR, ch);
        sensor.doSet();
        deselectAll(MUX1_ADDR);
    }

    // CSV header
    Serial.println("sensorID,Bx_G,By_G,Bz_G");
}

// ── Main loop ──────────────────────────────────────────────────────────────

void loop() {
    float Bx, By, Bz;

    // Board 0 — sensors 0-3
    for (uint8_t ch = 0; ch < 4; ch++) {
        if (readSensor(MUX0_ADDR, ch, Bx, By, Bz)) {
            Serial.print(ch);
            Serial.print(',');
            Serial.print(Bx, 4);
            Serial.print(',');
            Serial.print(By, 4);
            Serial.print(',');
            Serial.println(Bz, 4);
        } else {
            Serial.print(ch);
            Serial.println(",ERR,ERR,ERR");
        }
    }

    // Board 1 — sensors 4-7
    for (uint8_t ch = 0; ch < 4; ch++) {
        if (readSensor(MUX1_ADDR, ch, Bx, By, Bz)) {
            Serial.print(ch + 4);
            Serial.print(',');
            Serial.print(Bx, 4);
            Serial.print(',');
            Serial.print(By, 4);
            Serial.print(',');
            Serial.println(Bz, 4);
        } else {
            Serial.print(ch + 4);
            Serial.println(",ERR,ERR,ERR");
        }
    }

    delay(LOOP_DELAY_MS);
}

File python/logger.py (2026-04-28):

#!/usr/bin/env python3
"""
logger.py — USB-serial data logger for the MAG PCB magnetometer system.

Usage:
    python logger.py --port COM3 --output data.csv
    python logger.py --port /dev/ttyACM0 --output data.csv --duration 60

Output CSV columns:
    time_s, sensorID, Bx_G, By_G, Bz_G

Requirements:
    pip install pyserial pandas
"""

import argparse
import csv
import sys
import time
from datetime import datetime
from pathlib import Path

try:
    import serial
except ImportError:
    print("ERROR: pyserial not installed. Run: pip install pyserial")
    sys.exit(1)


def find_arduino_port():
    """Try to auto-detect the Arduino Nano Every serial port."""
    import serial.tools.list_ports
    ports = list(serial.tools.list_ports.comports())
    for p in ports:
        if "Arduino" in (p.manufacturer or "") or "ttyACM" in p.device:
            return p.device
    return None


def parse_args():
    parser = argparse.ArgumentParser(
        description="Log magnetometer CSV data from the MAG PCB board."
    )
    parser.add_argument(
        "--port", "-p",
        help="Serial port (e.g. COM3 or /dev/ttyACM0). Auto-detected if omitted."
    )
    parser.add_argument(
        "--baud", "-b",
        type=int, default=115200,
        help="Baud rate (default: 115200)"
    )
    parser.add_argument(
        "--output", "-o",
        default=f"data_{datetime.now().strftime('%Y%m%d_%H%M%S')}.csv",
        help="Output CSV filename (default: timestamped)"
    )
    parser.add_argument(
        "--duration", "-d",
        type=float, default=None,
        help="Recording duration in seconds (default: run until Ctrl-C)"
    )
    parser.add_argument(
        "--sensors", "-s",
        type=int, default=8,
        help="Expected number of sensors (default: 8). Used for progress display."
    )
    parser.add_argument(
        "--no-warmup",
        action="store_true",
        help="Skip the 5-second warmup delay"
    )
    return parser.parse_args()


def main():
    args = parse_args()

    # Resolve port
    port = args.port or find_arduino_port()
    if port is None:
        print("ERROR: Could not auto-detect Arduino port. Specify with --port.")
        sys.exit(1)
    print(f"Connecting to {port} at {args.baud} baud...")

    try:
        ser = serial.Serial(port, args.baud, timeout=2)
    except serial.SerialException as e:
        print(f"ERROR: Could not open port: {e}")
        sys.exit(1)

    # Flush startup messages
    time.sleep(2)
    ser.reset_input_buffer()

    if not args.no_warmup:
        print("Warming up for 5 seconds...")
        time.sleep(5)
        ser.reset_input_buffer()

    output_path = Path(args.output)
    print(f"Logging to {output_path}")
    print("Press Ctrl-C to stop.\n")

    t_start = time.time()
    row_count = 0
    error_count = 0

    with open(output_path, "w", newline="") as f:
        writer = csv.writer(f)
        writer.writerow(["time_s", "sensorID", "Bx_G", "By_G", "Bz_G"])

        try:
            while True:
                # Check duration limit
                elapsed = time.time() - t_start
                if args.duration and elapsed >= args.duration:
                    print(f"\nDuration limit reached ({args.duration} s).")
                    break

                raw = ser.readline()
                if not raw:
                    continue

                line = raw.decode("utf-8", errors="replace").strip()

                # Skip comments and header
                if not line or line.startswith("#") or line.startswith("sensor"):
                    print(f"  [{line}]")
                    continue

                parts = line.split(",")
                if len(parts) != 4:
                    continue

                sensor_id = parts[0]

                # Error rows from firmware
                if "ERR" in line:
                    error_count += 1
                    print(f"  SENSOR {sensor_id} ERROR (total errors: {error_count})")
                    continue

                try:
                    Bx = float(parts[1])
                    By = float(parts[2])
                    Bz = float(parts[3])
                except ValueError:
                    continue

                t_rel = round(time.time() - t_start, 4)
                writer.writerow([t_rel, sensor_id, Bx, By, Bz])
                f.flush()
                row_count += 1

                B_mag = (Bx**2 + By**2 + Bz**2) ** 0.5
                print(
                    f"  t={t_rel:8.3f}s  id={sensor_id}  "
                    f"Bx={Bx:+.4f}  By={By:+.4f}  Bz={Bz:+.4f}  "
                    f"|B|={B_mag:.4f} G"
                )

        except KeyboardInterrupt:
            print("\nStopped by user.")

    ser.close()
    elapsed = time.time() - t_start
    print(f"\nSaved {row_count} rows to {output_path}")
    print(f"Elapsed: {elapsed:.1f} s  |  Errors: {error_count}")

    # Quick sanity check
    if row_count > 0:
        _check_sensors(output_path, args.sensors)


def _check_sensors(csv_path: Path, expected_sensors: int):
    """Print a quick per-sensor summary after logging."""
    try:
        import pandas as pd
        df = pd.read_csv(csv_path)
        print("\nPer-sensor summary:")
        for sid in sorted(df["sensorID"].unique()):
            sub = df[df["sensorID"] == sid]
            B_mag = (sub["Bx_G"]**2 + sub["By_G"]**2 + sub["Bz_G"]**2) ** 0.5
            print(
                f"  Sensor {sid}: n={len(sub):4d}  "
                f"|B| mean={B_mag.mean():.4f} G  std={B_mag.std():.5f} G"
            )
        found = df["sensorID"].nunique()
        if found < expected_sensors:
            print(f"\nWARNING: only {found}/{expected_sensors} sensors in data.")
    except ImportError:
        pass   # pandas optional — skip summary


if __name__ == "__main__":
    main()

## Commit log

2026-04-28 Initial File Setup
    [MAG PCB FINAL-B_Cu.gbr, MAG PCB FINAL-B_Mask.gbr, MAG PCB FINAL-B_Paste.gbr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]
2026-04-29 Update board dimensions in README
